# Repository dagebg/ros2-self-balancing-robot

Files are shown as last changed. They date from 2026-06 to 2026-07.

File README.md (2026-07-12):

# ROS2 Self-Balancing Differential-Drive Robot




> A personal learning project — building a differential-drive robot from scratch
> using ROS2 on a Raspberry Pi 4, an ESP32 for real-time motor/sensor control,
> and a fully 3D-printed chassis.

**[Full documentation → dagebg.github.io/ros2-self-balancing-robot](https://dagebg.github.io/ros2-self-balancing-robot/)**

## Goals
The target end state is a two-wheeled self-balancing robot that:
- Balances itself using IMU sensor fusion feedback and a PID controller running on the ESP32
- The ESP32 runs a fast real-time balance loop (2xIMU → PID → motor commands)
- ROS2 on the Pi acts as the high-level layer, sending velocity targets without caring about the internal balance loop
- The chassis is being designed from scratch in Autodesk Fusion and Siemens NX and 3D-printed on a BambuLab P1S
- Controlling the controller over network with webapp

## Hardware

<p align="center">
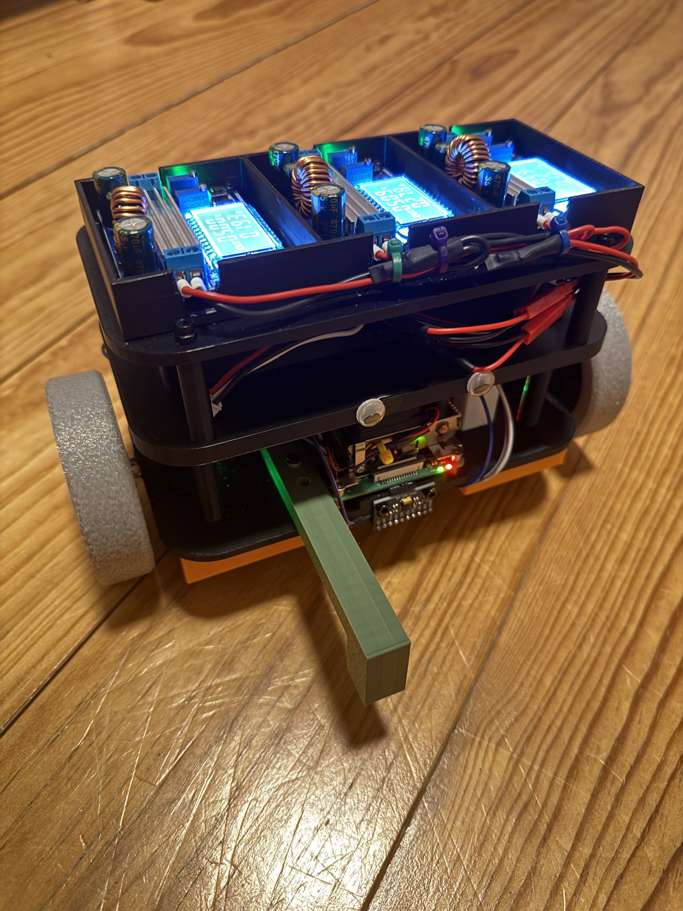
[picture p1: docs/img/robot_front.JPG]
  
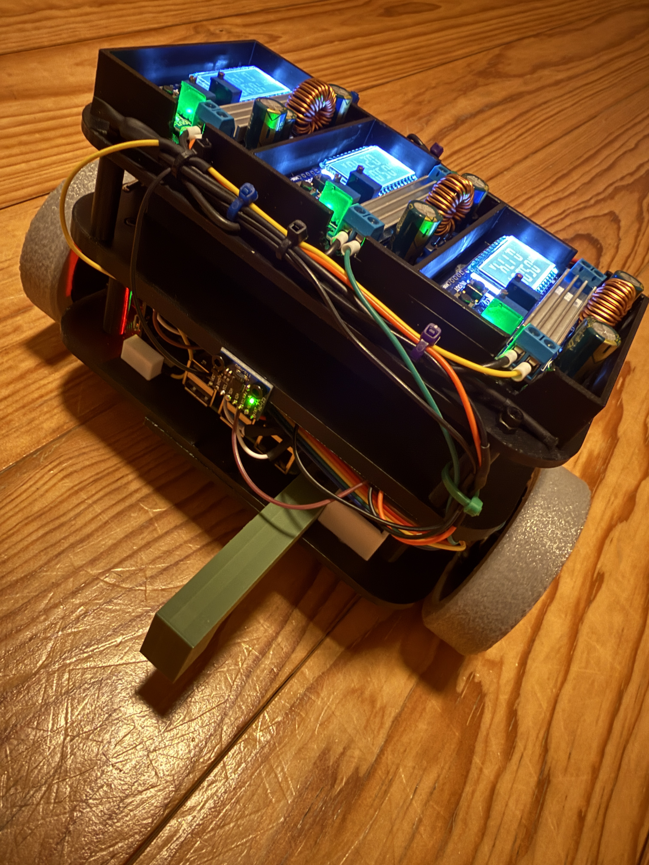
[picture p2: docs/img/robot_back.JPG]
  
</p>

| Component | Role |
|---|---|
| Raspberry Pi 4B 4GB | Main computer running ROS2 |
| ESP32 DevKit C V4 | Real-time motor control + IMU bridge |
| 2× N20 100 RPM + Hall encoders | Drive wheels + wheel odometry |
| TB6612FNG dual motor driver | Motor direction + PWM speed control |
| MPU-9250 9-DOF IMU | Accelerometer, gyroscope, magnetometer |
| MPU-6050 6-DOF IMU | Accelerometer, gyroscope|
| 2x 7.4V 2000mAh Li-Ion 2S | Main power source |
| 3x HW-140 DC-DC Buck Boost Converter | Power converter |
| 3D-printed chassis + wheels | Custom mechanical platform |

## Power System

The robot uses a multi-rail power architecture with dedicated buck converters for compute and embedded subsystems.  

<p align="center">
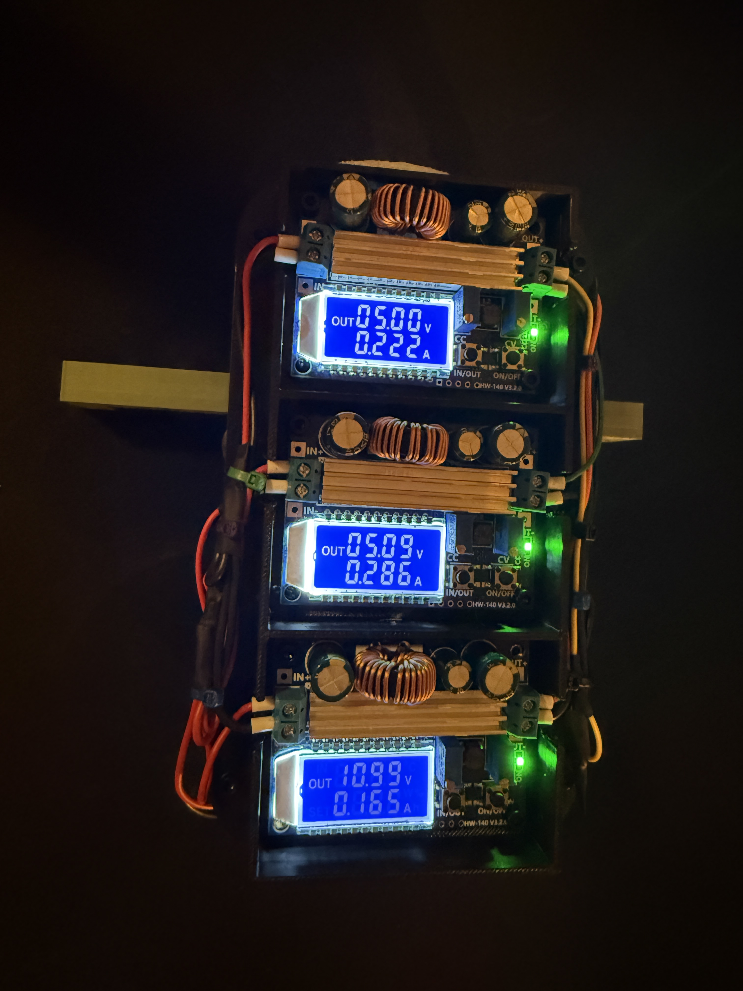
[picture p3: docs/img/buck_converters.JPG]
  
</p>

## Sensor Fusion Architecture

This robot uses two physically mounted IMUs at different locations and orientations for sensor fusion experimentation.

| IMU | Location | Orientation | Function |
|---|---|---|---|
| MPU-9250 | Lower deck | Facing forward | Primary IMU, 9-DOF orientation sensing |
| MPU-6050 | Second deck | Facing backward | Secondary IMU, comparison/reference sensing |

<p align="center">
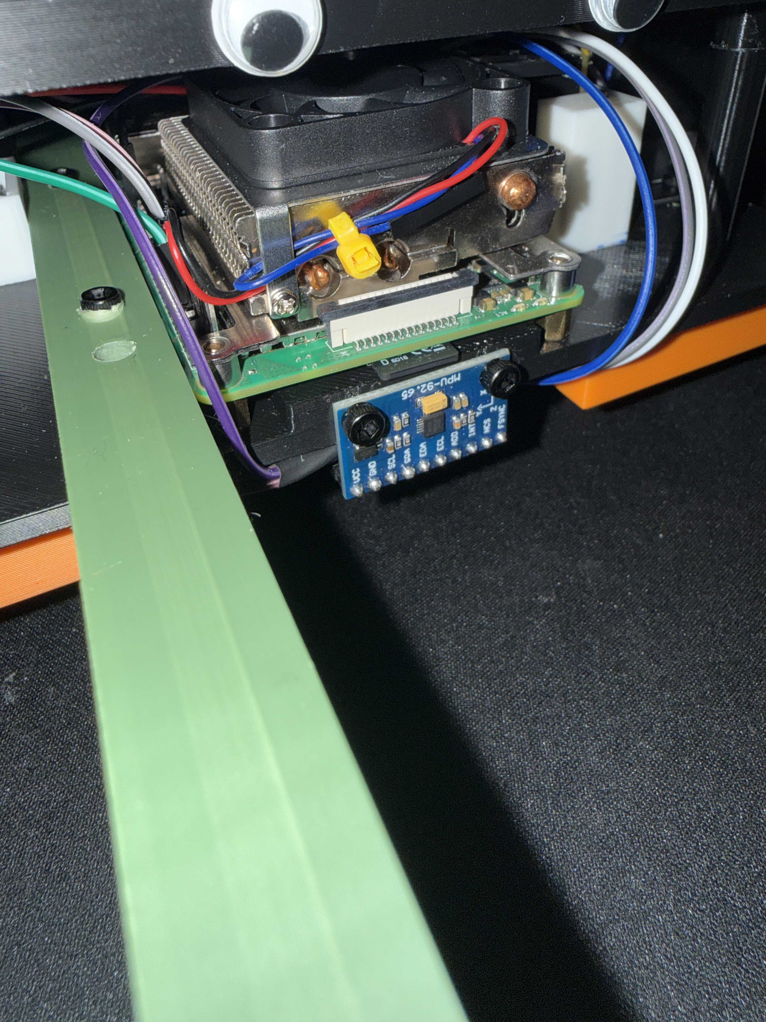
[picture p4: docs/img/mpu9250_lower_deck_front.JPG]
  
  
</p>

## Electronics Documentation

The robot electronics are documented in KiCad with a complete schematic of the main system.

<p align="center">
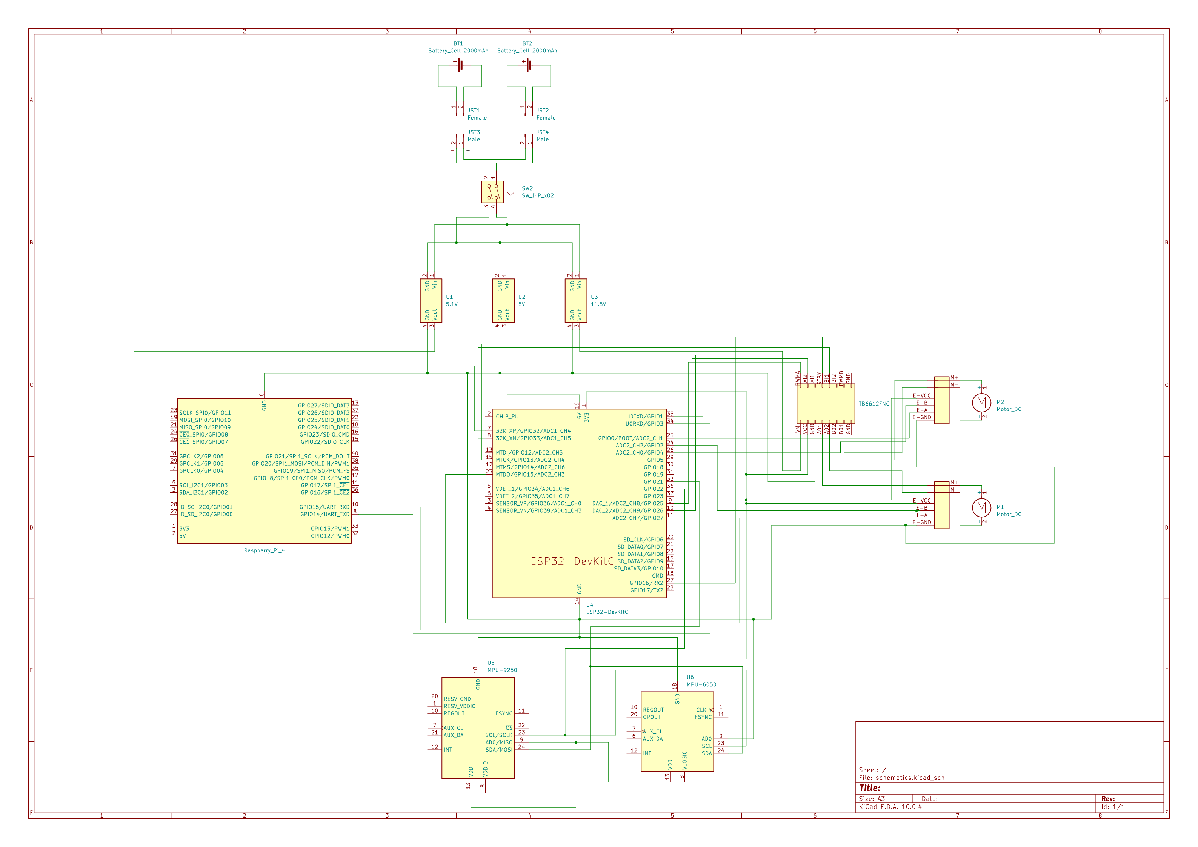
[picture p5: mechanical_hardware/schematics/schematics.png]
  
</p>

Files:
- [`schematics.kicad_sch`](mechanical_hardware/schematics/schematics.kicad_sch)
- [`schematics.pdf`](mechanical_hardware/schematics/schematics.pdf)

## Repository layout

```text
ros2-diffdrive-robot/
├── ros2_ws/              ROS2 workspace (packages: diff drive, navigation, etc.)
├── firmware/             ESP32 firmware (motor controller, IMU bridge)
├── mechanical_hardware   CAD design & wiring schematics     
└── docs/                 Architecture notes + Sphinx documentation
```

## Documentation

- [Full Sphinx docs](https://dagebg.github.io/ros2-diffdrive-robot/)
- [Architecture overview](docs/ARCHITECTURE.md)
- [Networking setup (Pi ↔ Fedora)](docs/networking-pi-fedora.md)

## Status

Early WIP — ROS2 workspace and firmware development in progress.

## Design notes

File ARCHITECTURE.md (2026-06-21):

# Architecture

## Components

- Dev PCs: Fedora Linux desktop and MacBook (used for development and SSH)
- Robot: Raspberry Pi 4 Model B 4GB running Ubuntu Server 24.04 and ROS2
- Microcontroller: ESP32 for motor and sensor control
- Hardware: TB6612FNG motor driver, 2× N20 motors with encoders, MPU-9250 IMU, Li-Ion batteries
- Mechanics: 3D-printed robot chassis, wheels, and support hardware

## Connections

- Fedora PC ↔ Raspberry Pi: direct Ethernet (SSH, internet sharing) for development  
  (see `docs/networking-pi-fedora.md` for details)

## ROS2 (planned)

- The Raspberry Pi runs ROS2 nodes that:
  - Subscribe to `/cmd_vel` for velocity commands
  - Publish odometry and IMU data
- The ESP32 handles:
  - Motor PWM output
  - Reading wheel encoders and IMU data
  - Sending this data back to the Raspberry Pi

This document will be updated as the system evolves.

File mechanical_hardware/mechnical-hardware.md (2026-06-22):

# Mechanical Hardware

This document tracks the mechanical design of the robot chassis and related 3D‑printed parts that I design and print myself, primarily using Autodesk Fusion 360 and my BambuLab P1S printer.

---

## Scope

The mechanical documentation in this file covers: 

- Overall chassis concept and footprint  
- Wheel, caster, and support geometry  
- Mounting points for electronics and sensors (mechanical aspects only)  
- 3D‑printing considerations and tolerances  
- Version history of my CAD models and printed prototypes  

---

## Third-Party CAD Models

The following CAD models were sourced from GrabCAD for reference and assembly visualisation. They are **not** designed by me. All rights remain with the original authors.

| File | Description | Author / Source |
|---|---|---|
| `N20_motor_encoder.stl` | N20 micro gear motor with magnetic encoder | GrabCAD Library — [N20 Motor with Magnetic Encoder](https://grabcad.com/library/n20-motor-with-magnetic-encoder-1) |
| `Raspberry Pi 4 Model B.STEP` | Raspberry Pi 4 Model B single-board computer | GrabCAD Library — [Raspberry Pi 4 Model B](https://grabcad.com/library/raspberry-pi-4-model-b-1) |
| `ESP32.STEP` | ESP32 DevKit C V4 development board | GrabCAD Library — [ESP32-DevKitC](https://grabcad.com/library/esp-32-1) |
| `MPU-9250.stp` | MPU-9250 9-DOF IMU breakout board | GrabCAD Library — [MPU-9250 Module](https://grabcad.com/library/mpu-9250-1) |
| `TB6612FNG_motor_driver.step` | TB6612FNG dual motor driver breakout board | GrabCAD Library — [TB6612FNG Motor Driver](https://grabcad.com/library/tb6612fng-1) |
| `Battery_Li-ion.stp` | 7.4 V 2S Li‑Ion battery pack (2000 mAh) | GrabCAD Library — [Li-Ion Battery Pack](https://grabcad.com/library/li-ion-battery-7-4v-1) |
| `Pi_cooler.step` | Heatsink / cooling assembly for Raspberry Pi 4 | GrabCAD Library — [Raspberry Pi 4 Cooler](https://grabcad.com/library/raspberry-pi-4-cooler-1) |

> **Note:** Third-party models in this folder are used solely for mechanical reference and assembly planning. They are not original designs of this project.

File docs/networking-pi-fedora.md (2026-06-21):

# Development Networking Setup (Raspberry Pi over Ethernet)

During development, the Raspberry Pi is connected directly to a Fedora laptop via Ethernet.  
The Fedora laptop shares its Wi‑Fi internet connection with the Pi and acts as a simple NAT gateway. [web:39][web:41][web:46][web:72]

## Topology

```text
[Internet] ⇄ [Wi‑Fi router] ⇄ [Fedora laptop]
                                   │
                                   │  eno1 (10.42.0.1/24)
                                   │
                              eth0 (10.42.0.100/24)
                                   │
                                 [Raspberry Pi]
```

- Fedora laptop:
  - Wi‑Fi interface: `wlp11s0` (internet)
  - Ethernet interface: `eno1` (to Pi)
- Raspberry Pi:
  - Ethernet interface: `eth0` (to Fedora)
  - Optional Wi‑Fi: `wlan0` (not used as default route in this setup)

---

## Raspberry Pi configuration (netplan + systemd‑resolved)

The Pi uses `systemd-networkd` via netplan and `systemd-resolved` for DNS.  
Static addressing and routing on `eth0` make the Pi always reachable at `10.42.0.100`, with the Fedora laptop `10.42.0.1` as its default gateway. [web:39][web:41][web:46][web:74]

Edit the netplan file (e.g. `/etc/netplan/50-cloud-init.yaml`):

```yaml
network:
  version: 2
  ethernets:
    eth0:
      optional: true
      dhcp4: false
      dhcp6: false
      addresses:
        - 10.42.0.100/24
      routes:
        - to: default
          via: 10.42.0.1

  wifis:
    wlan0:
      optional: true
      dhcp4: false
      regulatory-domain: "DE"
      addresses:
        - 192.168.178.200/24
      # no default route from Wi‑Fi
      nameservers:
        addresses: [8.8.8.8, 1.1.1.1]
      access-points:
        "FRITZ!Box 7362 SL":
          password: "<redacted>"
```

Apply and verify on the Pi:

```bash
sudo netplan apply

ip a show eth0
ip route show
resolvectl status

ping -c 3 10.42.0.1       # Fedora host
ping -c 3 8.8.8.8         # raw internet
ping -c 3 google.com      # DNS check
```

Expected on the Pi:

- `eth0` has `10.42.0.100/24`
- Route table contains:

  ```text
  default via 10.42.0.1 dev eth0
  10.42.0.0/24 dev eth0 proto kernel scope link src 10.42.0.100
  ```

- `resolvectl status` shows the configured DNS servers.

---

## Fedora laptop configuration

The Fedora laptop has a static IP on `eno1` for the Pi network, enables IPv4 forwarding, and uses a small script + systemd unit to set up NAT from `eno1` to `wlp11s0`. [web:72][web:74][web:78]

### 1. Static IP on `eno1`

Configure the `eno1` connection once via NetworkManager (replace the connection name as needed):

```bash
nmcli connection show            # find the connection for eno1

sudo nmcli connection modify "<eno1-connection-name>" \
  ipv4.addresses 10.42.0.1/24 \
  ipv4.method manual \
  connection.autoconnect yes

sudo nmcli connection down "<eno1-connection-name>" || true
sudo nmcli connection up "<eno1-connection-name>"

ip a show eno1
ip route show
```

Expected route:

```text
10.42.0.0/24 dev eno1 proto kernel scope link src 10.42.0.1
```

### 2. Enable IPv4 forwarding

Create a sysctl drop‑in so forwarding is enabled on every boot:

```bash
echo 'net.ipv4.ip_forward = 1' | sudo tee /etc/sysctl.d/99-ip-forward.conf
sudo sysctl --system
sysctl net.ipv4.ip_forward
# should print: net.ipv4.ip_forward = 1
```

This keeps the host ready to route traffic between `eno1` and `wlp11s0`. [web:72][web:78]

### 3. NAT + forwarding script

This script ensures IPv4 forwarding is on and injects the minimal iptables rules to masquerade traffic from the Pi network out via Wi‑Fi. [web:63][web:69][web:78]

Create `/usr/local/sbin/pi-nat.sh`:

```bash
sudo tee /usr/local/sbin/pi-nat.sh >/dev/null << 'EOF'
#!/usr/bin/env bash
# NAT + forwarding for Raspberry Pi on eno1 via wlp11s0

# ensure forwarding is on
sysctl -w net.ipv4.ip_forward=1

# add iptables rules only if missing
iptables -t nat -C POSTROUTING -o wlp11s0 -j MASQUERADE 2>/dev/null \
  || iptables -t nat -A POSTROUTING -o wlp11s0 -j MASQUERADE

iptables -C FORWARD -i eno1 -o wlp11s0 -j ACCEPT 2>/dev/null \
  || iptables -A FORWARD -i eno1 -o wlp11s0 -j ACCEPT

iptables -C FORWARD -i wlp11s0 -o eno1 -m state --state RELATED,ESTABLISHED 2>/dev/null \
  || iptables -A FORWARD -i wlp11s0 -o eno1 -m state --state RELATED,ESTABLISHED
EOF

sudo chmod +x /usr/local/sbin/pi-nat.sh
```

### 4. Systemd unit to apply NAT at boot

Create `/etc/systemd/system/pi-nat.service`:

```bash
sudo tee /etc/systemd/system/pi-nat.service >/dev/null << 'EOF'
[Unit]
Description=Enable NAT for Raspberry Pi on eno1 via wlp11s0
After=network-online.target
Wants=network-online.target

[Service]
Type=oneshot
ExecStart=/usr/local/sbin/pi-nat.sh
RemainAfterExit=yes

[Install]
WantedBy=multi-user.target
EOF

sudo systemctl daemon-reload
sudo systemctl enable --now pi-nat.service
```

On the Fedora host you can check:

```bash
sysctl net.ipv4.ip_forward
sudo iptables -L -n -v
sudo iptables -t nat -L -n -v
```

You should see:

- `net.ipv4.ip_forward = 1`
- A `MASQUERADE` rule in `POSTROUTING` for `wlp11s0`
- `FORWARD` rules allowing traffic between `eno1` and `wlp11s0`

---

## Usage

With both machines booted and the Ethernet cable connected:

From Fedora:

```bash
ping -c 3 10.42.0.100
ssh <user>@10.42.0.100
```

From the Pi:

```bash
ping -c 3 10.42.0.1     # Fedora host
ping -c 3 8.8.8.8       # internet connectivity
ping -c 3 google.com    # DNS resolution
```

If these checks pass, the Pi has:

- Stable Ethernet SSH at `10.42.0.100`
- Internet access through the Fedora host
- Working DNS for package installation and ROS2 development

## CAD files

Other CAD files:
mechanical_hardware/CAD/2.54 mm DUPONT MALE PIN HEADER, IO, 2X20, RPi4ModelB.prt
mechanical_hardware/CAD/2.54 mm DUPONT MALE PIN HEADER, POE, 2X2, RPi4ModelB.prt
mechanical_hardware/CAD/2X USB2.0 PORTS, RPi4ModelB.prt
mechanical_hardware/CAD/2X USB3.0 PORTS, RPi4ModelB.prt
mechanical_hardware/CAD/3x4x2mm_tact_button.prt
mechanical_hardware/CAD/8x1 male header pins.prt
mechanical_hardware/CAD/91D77 D9WHV 778K, 4 GB LPDDR4 SDRAM, RPi4ModelB.prt
mechanical_hardware/CAD/Broadcom BCM2711B0 CPU, RPi4ModelB.prt
mechanical_hardware/CAD/Broadcom BCM54213PE Gigabit Ethernet Transceiver, RPi4ModelB.prt
mechanical_hardware/CAD/CAPC-0603-T0.9-BN.prt
mechanical_hardware/CAD/Camera Connector, RPi4ModelB.prt
mechanical_hardware/CAD/Cypress CYW43455 Wireless Module Cover, RPi4ModelB.prt
mechanical_hardware/CAD/Display Connector, RPi4ModelB.prt
mechanical_hardware/CAD/ESP32-chip.prt
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

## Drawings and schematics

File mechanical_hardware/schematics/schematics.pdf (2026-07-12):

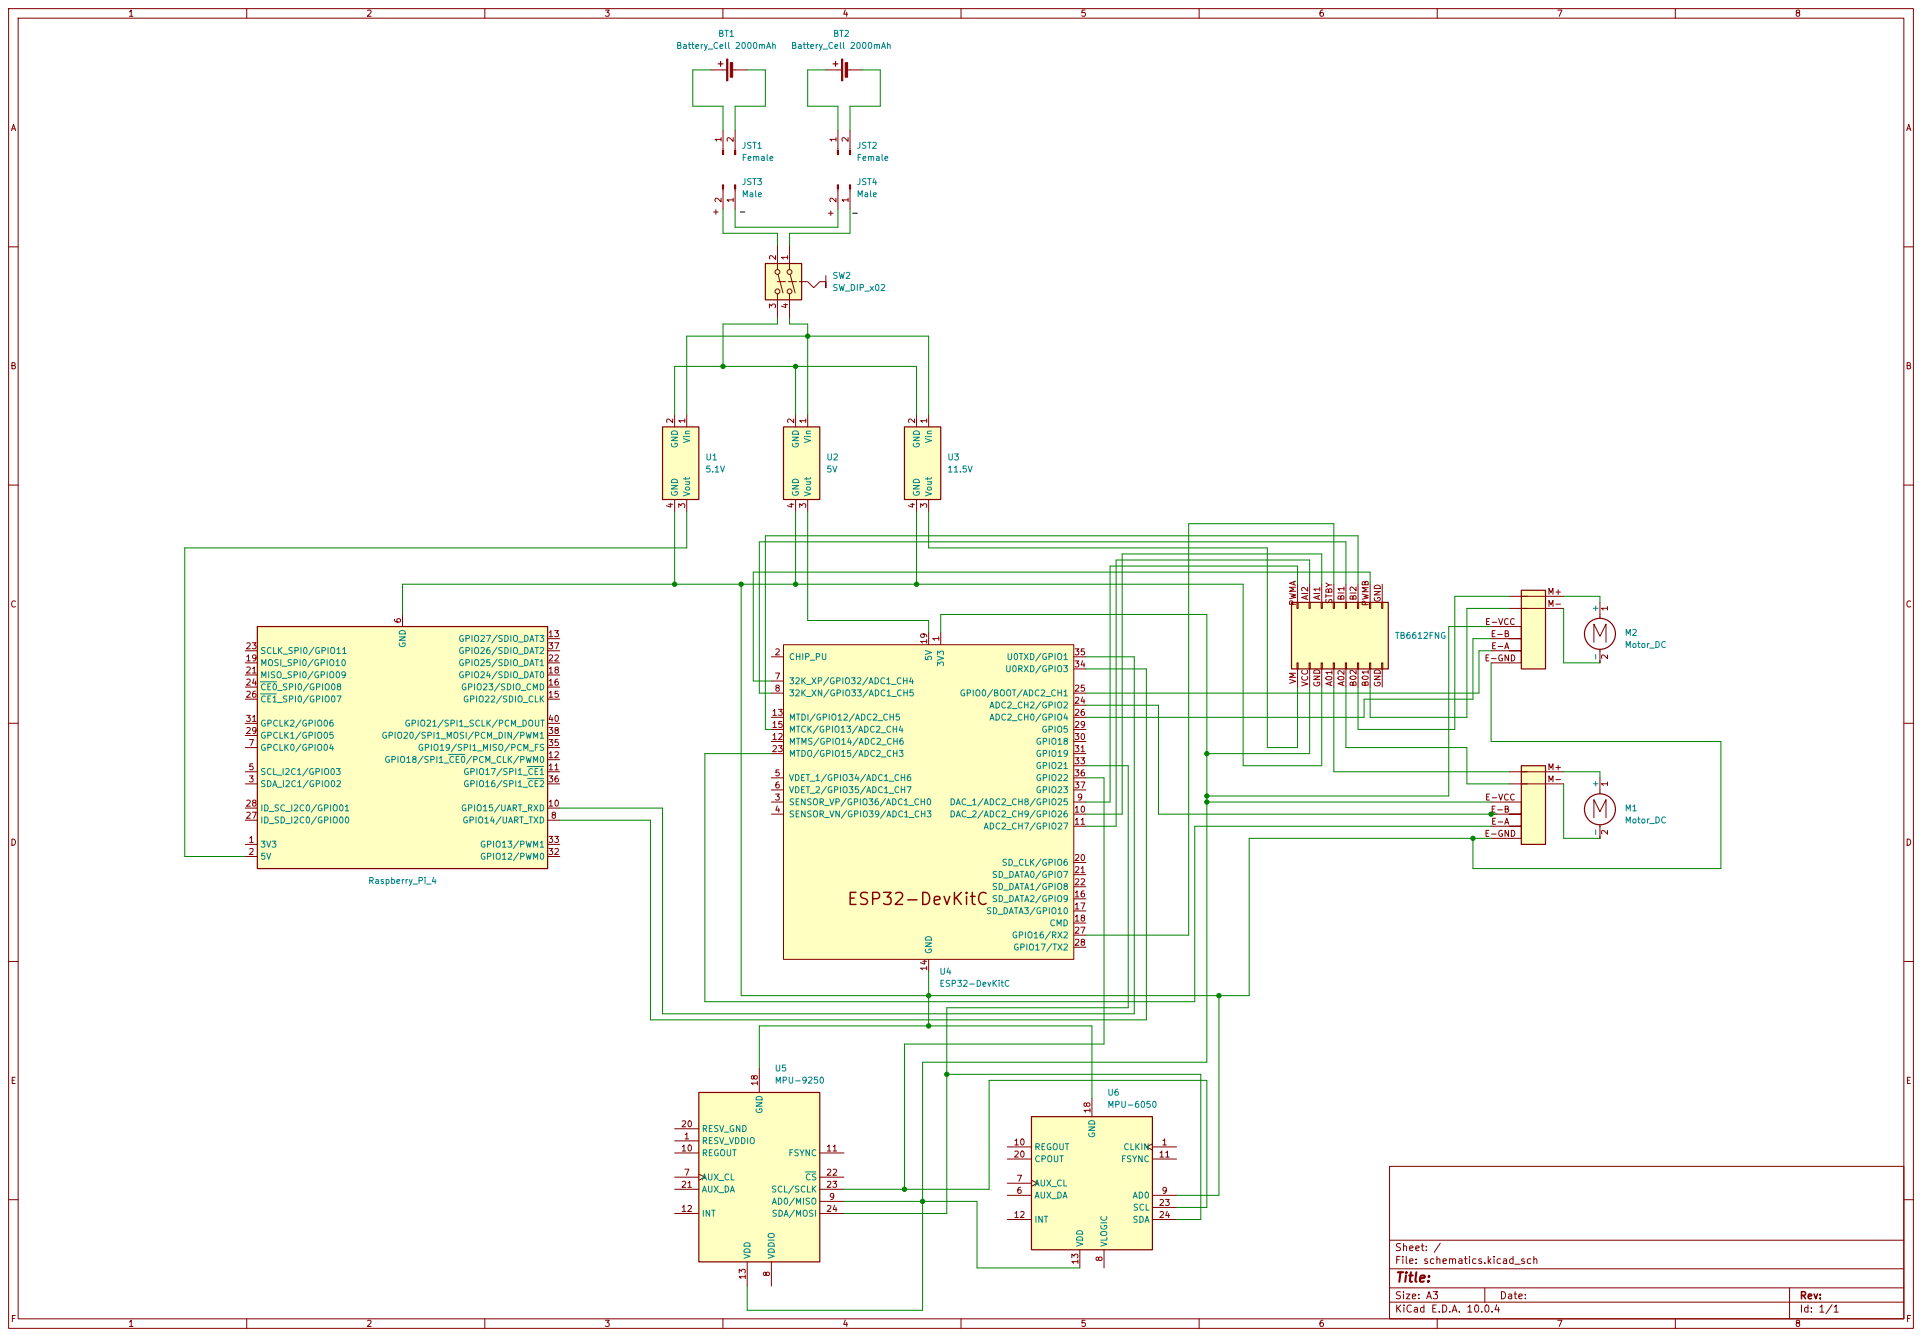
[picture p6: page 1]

Size: A3 | Rev:
KiCad E.D.A. 10.0.4 | Id: 1/1

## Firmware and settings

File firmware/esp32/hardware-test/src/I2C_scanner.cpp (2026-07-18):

#include <Arduino.h>
#include <Wire.h>

void setup() {
  Serial.begin(115200);
  Wire.begin(21,22);
  Serial.println("I2C Scanner");
  delay(1000);
  Serial.println("Scanning I2C bus...");

  for (byte addr = 1; addr < 127; addr++ ) {
    Wire.beginTransmission(addr);
    byte error = Wire.endTransmission();

    if (error == 0) {
      Serial.print("I2C device found at address 0x");
      if (addr < 16) {
        Serial.print("0");
      }
      Serial.println(addr, HEX);
    } else if (error == 4) {
      Serial.print("Unknown error at address 0x");
      if (addr < 16) {
        Serial.print("0");
      }
      Serial.println(addr, HEX);
    }
  }
}

void loop() {
  // Nothing to do here
}

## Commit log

2026-06-22 docs: add all third-party CAD model attributions
2026-06-23 kicad schematics
    [schematics.kicad_sch]
2026-07-05 schematics backup
    [schematics.kicad_sch]
2026-07-05 backup schematics
    [schematics.kicad_sch]
2026-07-05 Update motor specifications in README
2026-07-09 fixed schematics
    [schematics.kicad_sch]
2026-07-11 changed gitignore to ignore kicad git
2026-07-12 finished schematics & pics
2026-07-12 Add electronics documentation to README
    Added electronics documentation section with schematic files.
2026-07-12 rendered schematics
2026-07-12 Fix file paths in README for schematics
2026-07-12 Simplify schematic file links in README
    Updated file links in README to simplify paths.
2026-07-12 Change schematic image from PDF to PNG
    Updated the schematic image format from PDF to PNG.
2026-07-12 Update schematic image width in README
2026-07-12 plot backgprund color schematics
2026-07-18 created platformio project for hardware test - esp, sensors, motors
2026-07-18 i2c scanner
2026-10-10 docs: move architecture and networking notes into the Sphinx tree
    The architecture page gains a system diagram, a responsibility split
    between ESP32 and Pi, and a connection table. The networking guide loses
    leftover [web:NN] citation markers. Adds a milestone roadmap page and
    fixes the README links that pointed at the old locations.
2026-10-10 docs: add hardware reference derived from the KiCad netlist
    Bill of materials, IMU placement, ESP32 pinout, power rails and a
    known-issues page. The pinout comes from the exported netlist rather
    than the drawing, which surfaced that the TB6612 outputs are not
    connected to the motor connectors in the schematic. Also marks two CAD
    files listed in mechanical-hardware.md that are not in the repository.
2026-10-10 docs: add ADR process with the first three decisions
    ADR-0001 records the ADR process itself, ADR-0002 the move to modern
    C++17 on Arduino-ESP32, and ADR-0003 the custom COBS/CRC16 UART protocol
    chosen over micro-ROS.
2026-10-10 build(docs): switch to MyST with Mermaid and a Doxygen API reference
    - Enable myst_parser; Mermaid fences render as diagrams in Sphinx and
    on GitHub alike.
    - Add a Doxyfile (headers only) that conf.py runs on every build, so
    the breathe API pages never go stale.
    - Replace index.rst with a structured index.md, add the missing _static
    directory and pin the documentation dependencies.
    - Fix the project name to match the repository.
2026-10-10 build: pin development tools and add an editorconfig
    requirements-dev.txt now pins every tool CI uses (PlatformIO, ruff,
    clang-format, pre-commit, cmake, ninja, gcovr). ruff targets Python 3.12
    with bugbear, pyupgrade, isort and simplify rules, and now also lints the
    Sphinx config.

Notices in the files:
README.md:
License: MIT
